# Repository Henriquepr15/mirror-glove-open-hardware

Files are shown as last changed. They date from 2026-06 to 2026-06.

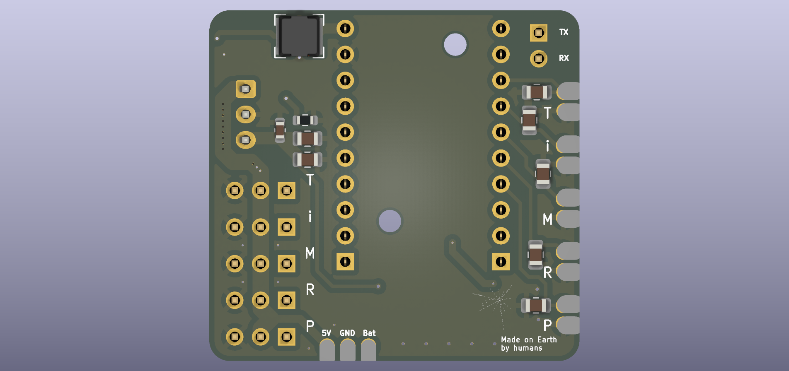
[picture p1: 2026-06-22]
hardware/images/pcb_3d_bottom_render.png

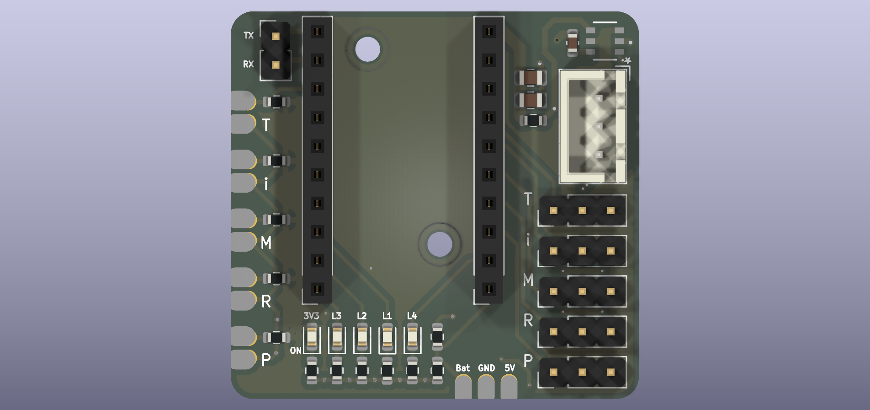
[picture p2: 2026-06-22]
hardware/images/pcb_3d_top_render.png

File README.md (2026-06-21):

# Mirror Glove Open Hardware

Mirror Glove is an open hardware wearable interface designed for finger motion capture using flexible resistive sensors, an ESP32-C6 Super Mini microcontroller, signal conditioning circuitry, firmware, and a labeled gesture dataset for assistive technology research.

The project was developed as an experimental platform for acquiring analog signals generated by finger flexion. The system uses five flexible sensors positioned on a glove, one for each finger, and converts finger movement into measurable electrical signals. These signals can be used for gesture analysis, motion mirroring, actuator control experiments, and preliminary gesture classification in external computational environments.

## Project goals

* Capture finger motion using five flexible resistive sensors.
* Condition analog signals using voltage dividers and passive RC low-pass filtering.
* Read sensor signals using an ESP32-C6 Super Mini.
* Organize sensor data into a structured gesture dataset.
* Support experimental motion mirroring using a transmitter and receiver architecture.
* Provide open hardware documentation for assistive technology, wearable interfaces, embedded systems, and prosthetics research.

## Repository structure

* `hardware/`: PCB design files, schematics, layout images, Gerber files, and hardware-related documentation.
* `firmware/`: ESP32 firmware for the glove transmitter and receiver/actuator unit.
* `docs/`: build instructions, calibration instructions, testing procedures, and operation notes.
* `bom/`: bill of materials with component specifications and quantities.
* `data/`: raw and processed datasets generated from the Mirror Glove.
* `analysis/`: scripts and notebooks used for signal analysis, PCA, machine learning models, and result generation.
* `figures/`: images, diagrams, plots, confusion matrices, and graphical outputs used in the manuscript.

## Intended audience

This project is intended for undergraduate students, researchers, hardware developers, embedded systems developers, assistive technology researchers, and engineers working with wearable interfaces, gesture capture, rehabilitation engineering, robotics, and experimental prosthetics.

## Skills required

* Soldering and PCB assembly: intermediate to advanced.
* ESP32 firmware development: intermediate.
* KiCad or PCB design review: intermediate.
* Python-based signal analysis: basic to intermediate.
* Wearable prototype assembly: basic to intermediate.

## Hardware overview

The Mirror Glove prototype consists of a wearable glove with five flexible resistive sensors connected to a custom PCB. Each sensor is associated with one finger: thumb, index, middle, ring, and pinky. The analog signal from each sensor is conditioned using a voltage divider and passive RC low-pass filtering before being read by the ESP32 analog inputs.

The hardware was designed to support data acquisition, gesture recording, signal analysis, and future expansion for actuator control or wireless motion mirroring using ESP32-based communication.

## Software overview

The firmware is divided into two main modules:

1. Glove transmitter firmware: reads the five flexible sensors and organizes the sensor values.
2. Receiver/actuator firmware: receives sensor data and can convert proportional finger motion values into actuator commands.

Artificial intelligence and gesture classification are not embedded in the ESP32 firmware in the current version. Machine learning analyses are performed externally using the collected dataset.

## Dataset

The dataset contains labeled samples collected from the Mirror Glove sensors during gesture execution. Each sample includes time information, gesture labels, and the readings from the five flexible sensors. The dataset is intended for signal analysis, exploratory visualization, and preliminary supervised gesture classification.

## Documentation status

This repository is under active organization for submission to the Journal of Open Hardware. Build instructions, calibration procedures, testing instructions, design files, firmware, datasets, and analysis scripts are being organized to support replication and peer review.

## Licenses

Hardware files are intended to be licensed under the CERN Open Hardware Licence Version 2 - Permissive (CERN-OHL-P-2.0).

Software and firmware files are intended to be licensed under the MIT License.

Documentation is intended to be licensed under Creative Commons Attribution 4.0 International (CC-BY 4.0).

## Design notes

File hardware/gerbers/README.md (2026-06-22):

# Gerber fabrication files

This folder contains the Gerber and drill files exported from the Mirror Glove ESP32-C6 Super Mini PCB design.

These files correspond to the prototype version used for experimental validation and open hardware documentation.

## Important note

The current PCB design is provided as an experimental/as-built prototype version. The KiCad Design Rule Checker reported violations mainly related to custom footprints, courtyard definitions, library matching, and layout details.

The board files are shared to support transparency, review, modification, and replication of the prototype. Before manufacturing a new batch, users should open the project in KiCad, run ERC/DRC checks, review the reported violations, and adjust the design according to the fabrication requirements of the selected PCB manufacturer.

This project is not a certified medical device and the PCB files should not be used for clinical or safety-critical applications without additional validation.

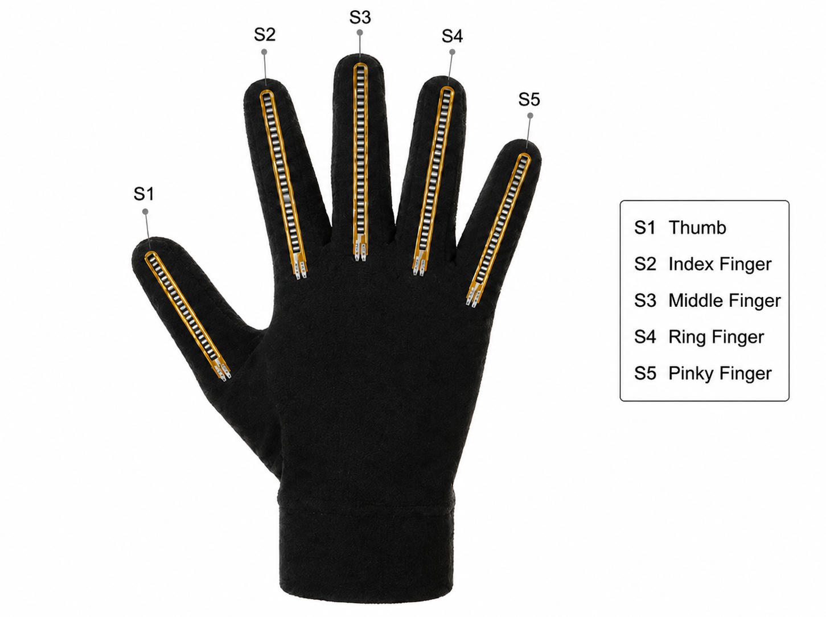
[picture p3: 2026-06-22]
hardware/images/Sensorized Glove Prototype with Flex Sensors.png

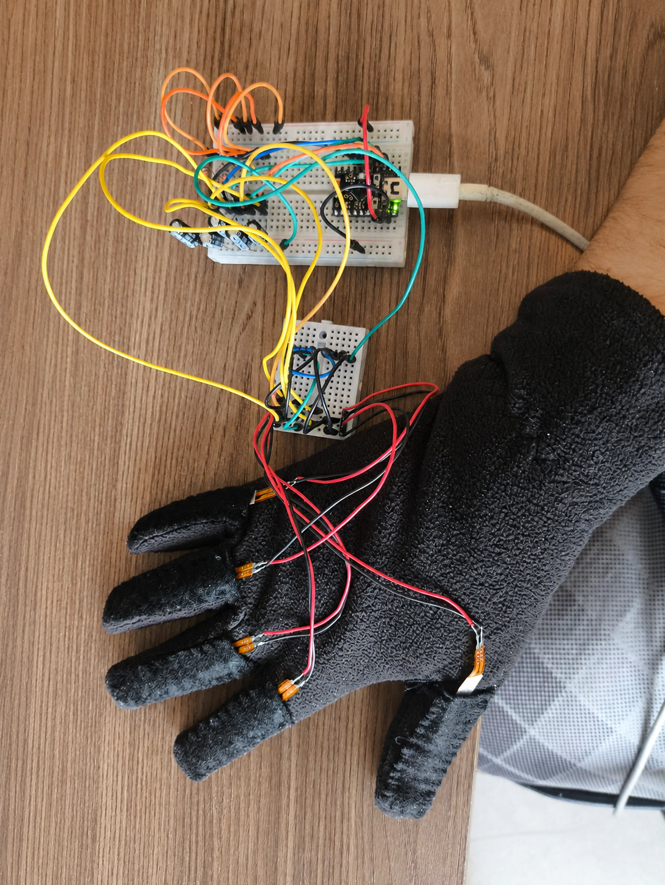
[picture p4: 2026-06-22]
hardware/images/early_prototype_breadboard_glove_1_.jpg

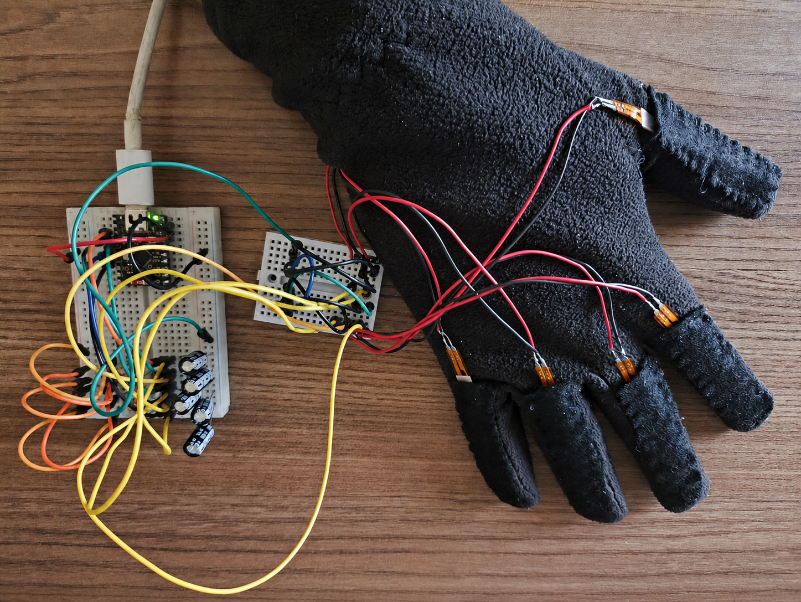
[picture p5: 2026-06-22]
hardware/images/early_prototype_breadboard_glove_2_.jpg

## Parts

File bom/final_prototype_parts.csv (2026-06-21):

Item | Component | Specification | Quantity | Notes
01 | Fabric glove | Base wearable glove | 1 | Physical support for the five flexible sensors
02 | Flexible resistive sensor | Flex sensor for finger bending measurement | 5 | One sensor per finger
03 | ESP32-C6 Super Mini | ESP32-C6 development board | 1 | Main acquisition microcontroller
04 | Mirror Glove printed circuit board | Custom PCB | 1 | Main board for signal conditioning and sensor connections
05 | SMD resistor | 68 kΩ | 5 | Voltage divider resistor for each flex sensor
06 | SMD capacitor | 10 µF | 5 | Passive RC low-pass filtering for sensor channels
07 | SMD capacitor | 100 nF | 2 | Decoupling or auxiliary filtering
08 | SMD capacitor | 4.7 µF | 2 | Decoupling or auxiliary filtering
09 | SMD LED | 0603 package | 5 | Optional visual indication or debugging
10 | Sensor connector | 1x02 connector | 5 | Sensor-to-PCB connection
11 | Pin connector | 1x10 connector | 2 | Board interconnection
12 | JST connector | 1x03 connector | 1 | Power or peripheral connection
13 | Wires or connection cables | Flexible wires | As needed | Used to connect sensors and PCB
14 | USB cable | Compatible with ESP32 board | 1 | Used for programming and power

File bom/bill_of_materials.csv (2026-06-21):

Item | Component | Specification | Unit | Quantity | Category | Used in final prototype | Notes
01 | Fabric glove | Base wearable glove | pcs | 1 | Wearable structure | Yes | Used as the physical support for the flexible sensors
02 | Flexible resistive sensor | Flex sensor for finger bending measurement | pcs | 5 | Sensor | Yes | One sensor positioned on each finger
03 | ESP32-C6 Super Mini | ESP32-C6 development board | pcs | 2 | Microcontroller | Yes | One board for acquisition and one optional board for receiver or actuator tests
04 | Mirror Glove printed circuit board | Custom PCB | pcs | 2 | PCB | Yes | Custom board developed for the Mirror Glove prototype
05 | SMD resistor | 68 kΩ | pcs | 5 | Passive component | Yes | Used in the voltage divider circuits for the flex sensors
06 | SMD capacitor | 10 µF | pcs | 7 | Passive component | Yes | Used mainly for passive RC low-pass filtering and signal stabilization
07 | SMD resistor | 300 Ω | pcs | 4 | Passive component | Yes | Used in auxiliary circuit sections
08 | SMD resistor | 10 kΩ | pcs | 1 | Passive component | Yes | Used in auxiliary circuit sections
09 | SMD resistor | 5.1 kΩ | pcs | 3 | Passive component | Yes | Used in auxiliary circuit sections
10 | SMD resistor | 1 kΩ | pcs | 3 | Passive component | Yes | Used in auxiliary circuit sections
11 | SMD resistor | 100 kΩ | pcs | 1 | Passive component | Yes | Used in auxiliary circuit sections
12 | SMD resistor | 13.7 kΩ | pcs | 1 | Passive component | Yes | Used in auxiliary circuit sections
13 | SMD capacitor | 100 nF | pcs | 2 | Passive component | Yes | Used for decoupling or auxiliary filtering
14 | SMD capacitor | 4.7 µF | pcs | 2 | Passive component | Yes | Used for decoupling or auxiliary filtering
15 | SMD LED | 0603 package | pcs | 5 | Indicator | Yes | Used as visual indicators or debugging elements
16 | Sensor connector | 1x02 connector | pcs | 5 | Connector | Yes | Used to connect the flexible sensors to the PCB
17 | Pin connector | 1x10 connector | pcs | 2 | Connector | Yes | Used for board interconnection
18 | Pin connector | 1x02 connector | pcs | 1 | Connector | Yes | Used for auxiliary connection
19 | JST connector | 1x03 connector | pcs | 1 | Connector | Yes | Used for power or peripheral connection
20 | Test point | PCB test point | pcs | 1 | Testing interface | Yes | Used for measurement or debugging
21 | Inductor | 3.3 µH | pcs | 1 | Power component | Yes | Associated with the power regulation circuit in specific PCB versions
22 | Integrated circuit | LMR51430YFDDCR | pcs | 1 | Power component | Yes | Used in the buck converter section in PCB versions that include power regulation
23 | Wires or connection cables | Flexible wires or jumper cables | m | 10 | Wiring | Yes | Used for sensor and prototype connections
24 | Soldering iron | Electronic soldering tool | pcs | 1 | Assembly tool | No | Used for PCB assembly
25 | Solder wire | Electronic solder wire | pcs | 1 | Assembly tool | No | Used for PCB assembly
26 | Digital multimeter | General-purpose digital multimeter | pcs | 1 | Testing tool | No | Used for continuity voltage and resistance measurements
27 | Power supply or USB port | USB or external power source | pcs | 1 | Power or testing tool | No | Used to power the prototype during tests
28 | USB cable | Compatible with the ESP32 board | pcs | 2 | Programming and power | No | Used for firmware upload and board power
29 | Computer | Computer for firmware and data analysis | pcs | 1 | Development tool | No | Used for programming data acquisition and analysis
30 | Arduino IDE or PlatformIO | Firmware development environment | pcs | 1 | Software | No | Used to develop and upload ESP32 firmware
31 | KiCad | PCB design software | unit | 1 | Software | No | Used for schematic and PCB design
32 | Python | Python programming environment | unit | 1 | Software | No | Used for signal analysis and machine learning experiments
33 | Arduino Uno | Arduino development board | unit | 2 | Development or test board | No | Used in preliminary bench tests
34 | Breadboard | Protoboard for preliminary tests | pcs | 2 | Development tool | No | Used for initial sensor and circuit validation
35 | PTH capacitors | Various through-hole capacitors for tests | pcs | 5 | Development or test component | No | Used in preliminary filtering and validation tests
36 | PTH resistors | Various through-hole resistors for tests | pcs | 5 | Development or test component | No | Used in preliminary voltage divider and validation tests
37 | Adjustable bench power supply | Adjustable laboratory power supply | pcs | 1 | Testing tool | No | Used for controlled power tests
38 | Electrical tape | Insulating tape | roll | 1 | Assembly support | No | Used for insulation and temporary fixation
39 | Servomotor | Hobby servo motor for actuator tests | pcs | 5 | Actuator | Optional | Used for experimental motion mirroring tests

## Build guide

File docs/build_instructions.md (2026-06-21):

# Mirror Glove Build Instructions

This document describes the basic assembly procedure for the Mirror Glove open hardware prototype. The system consists of a wearable glove with five flexible resistive sensors, a custom PCB, signal conditioning components, an ESP32-C6 Super Mini microcontroller, firmware for data acquisition, and optional receiver-side actuator control.

## 1. Required materials

The main materials required to build the Mirror Glove prototype are:

* 1 fabric glove
* 5 flexible resistive sensors
* 1 custom Mirror Glove PCB
* 1 ESP32-C6 Super Mini module
* 5 fixed resistors for voltage dividers
* Capacitors for passive RC low-pass filtering
* Sensor connectors
* Pin headers or board connectors
* Jumper wires or flexible wires
* USB cable
* Computer with Arduino IDE or PlatformIO
* Soldering iron and solder wire
* Multimeter
* Optional: receiver ESP32 board and servomotors for motion mirroring experiments

A complete bill of materials is provided in `bom/bill_of_materials.csv`.

## 2. Sensor positioning on the glove

Place one flexible resistive sensor on each finger of the glove. The sensors should be aligned with the natural flexion axis of the fingers.

Suggested mapping:

* Sensor 1: thumb
* Sensor 2: index finger
* Sensor 3: middle finger
* Sensor 4: ring finger
* Sensor 5: pinky finger

Each sensor should be positioned longitudinally on the dorsal side of the glove so that finger flexion causes mechanical bending of the sensor.

## 3. Sensor wiring

Each flexible sensor is connected as part of a voltage divider circuit. The voltage divider converts the resistance variation of the flexible sensor into an analog voltage that can be read by the ESP32 analog-to-digital converter.

General connection:

* One terminal of the flexible sensor is connected to the supply/reference side of the voltage divider.
* The other terminal is connected to the analog reading node.
* A fixed resistor is connected between the analog reading node and the reference/ground side, according to the selected circuit configuration.
* The analog reading node is connected to one ESP32 analog input.

Repeat this circuit for all five sensors.

## 4. Signal conditioning

A passive RC low-pass filter is used to reduce fast fluctuations and noise in the analog readings. A capacitor is connected between the analog reading node and GND.

The RC filter is intended to attenuate fast oscillations caused by electrical noise, unstable contact, mechanical vibration, and touch-related interference, while preserving the slower signal variations associated with finger flexion.

## 5. PCB assembly

Solder the components onto the Mirror Glove PCB according to the schematic and board layout files provided in the `hardware/` directory.

Recommended assembly order:

1. Solder passive SMD components such as resistors and capacitors.
2. Solder connectors for the flexible sensors.
3. Solder pin headers or connectors for the ESP32-C6 Super Mini module.
4. Inspect all solder joints visually.
5. Use a multimeter to check for short circuits between power and ground.
6. Connect the ESP32-C6 Super Mini to the PCB.
7. Connect the five flexible sensors to the corresponding sensor inputs.

## 6. Firmware upload

Upload the transmitter firmware to the ESP32-C6 Super Mini using Arduino IDE or PlatformIO.

The firmware should perform the following functions:

* Read the five analog sensor channels.
* Associate each sensor value with its corresponding finger.
* Send readings to the serial monitor or store/transmit the data.
* Optionally transmit the values to a receiver board for motion mirroring.

Firmware files are provided in the `firmware/` directory.

## 7. Initial power-on test

Before wearing the glove, perform a basic power-on test:

1. Connect the ESP32 board to the computer through USB.
2. Open the serial monitor.
3. Check whether five sensor readings are being displayed.
4. Move each sensor manually and verify whether the corresponding reading changes.
5. Confirm that no channel is fixed, saturated, disconnected, or unstable.

## 8. Glove integration

After validating each sensor channel individually, attach the sensors permanently or semi-permanently to the glove. The attachment method should allow the sensor to bend naturally with the finger while avoiding excessive mechanical stress at the sensor terminals.

Recommended practices:

* Avoid sharp bends near the sensor terminals.
* Use flexible wires when possible.
* Provide strain relief near connection points.
* Keep sensor cables organized to avoid pulling during finger movement.

## 9. Calibration before use

Before collecting data, calibrate each sensor by recording approximate minimum and maximum ADC values for each finger.

The calibration procedure is described in `docs/calibration.md`.

## 10. Functional test

After assembly and calibration, perform the following functional test:

1. Wear the glove.
2. Open the serial monitor or data acquisition interface.
3. Move each finger individually.
4. Verify whether the expected sensor channel responds.
5. Perform simple gestures such as open hand, closed hand, pointing, pinch, OK gesture, and thumbs-up.
6. Record a short dataset and inspect whether the readings are coherent.

Testing procedures are described in `docs/testing.md`.

## 11. Notes and limitations

This prototype is intended for experimental data acquisition and research in wearable interfaces, assistive technology, gesture analysis, and prosthetics-related studies. It is not a medical device and should not be used for clinical decision-making without further validation, ethical approval, and regulatory assessment.

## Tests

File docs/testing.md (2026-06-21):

# Mirror Glove Testing Procedure

This document describes the basic testing procedure used to validate the Mirror Glove open hardware prototype.

## 1. Purpose

The testing procedure verifies whether the Mirror Glove prototype can acquire coherent signals from five flexible resistive sensors positioned on a wearable glove.

The tests evaluate:

- Electrical continuity.
- Sensor response.
- Analog reading stability.
- Effect of the RC low-pass filter.
- Individual finger response.
- Gesture recording.
- Optional actuator response.

## 2. Electrical inspection

Before powering the circuit:

1. Visually inspect all solder joints.
2. Check the orientation and placement of connectors.
3. Use a multimeter to verify that there is no short circuit between power and ground.
4. Verify continuity between each sensor connector and the corresponding analog input.
5. Inspect loose wires or unstable connections.

## 3. Power-on test

1. Connect the ESP32-C6 Super Mini to the computer using a USB cable.
2. Open the serial monitor or data acquisition interface.
3. Confirm that the firmware starts correctly.
4. Verify whether five sensor channels are displayed.
5. Confirm that no channel is fixed, saturated, disconnected, or showing abnormal noise.

## 4. Individual sensor test

Test each finger sensor separately:

1. Keep the glove still.
2. Move only one finger.
3. Observe whether the expected channel changes.
4. Return the finger to the relaxed position.
5. Repeat the process for all five fingers.

Suggested mapping:

- Thumb
- Index finger
- Middle finger
- Ring finger
- Pinky finger

## 5. Static stability test

With the glove at rest:

1. Keep the hand still for a short period.
2. Record the raw ADC readings.
3. Observe whether the values remain stable.
4. Compare filtered and unfiltered readings when available.

This test helps evaluate whether the RC low-pass filter reduces fast fluctuations and signal instability.

## 6. Gesture test

Perform simple gestures and verify whether the sensor readings change coherently:

- Open hand.
- Closed hand.
- Pointing gesture.
- Pinch gesture.
- OK gesture.
- Thumbs-up gesture.

Each gesture should produce a different combination of sensor readings.

## 7. Dataset recording test

To validate data collection:

1. Define the gesture label before recording.
2. Record a sequence of samples.
3. Save the timestamp, gesture label, and five sensor readings.
4. Repeat the process for all target gestures.
5. Inspect the dataset for missing values, mislabeled samples, or unstable channels.

## 8. Optional receiver and actuator test

If the receiver board and servomotors are used:

1. Upload the receiver firmware to the second ESP32 board.
2. Confirm that the receiver obtains the transmitted sensor data.
3. Connect the servomotors.
4. Map each sensor value to the corresponding actuator.
5. Move each finger and observe whether the corresponding servo responds proportionally.

## 9. Known limitations

The current prototype is intended for experimental validation. The tests verify signal acquisition and preliminary gesture differentiation, but they do not validate clinical use, long-term durability, anatomical accuracy, or medical safety.

Further tests are required to evaluate:

- Long-term sensor stability.
- Repeated wearing and repositioning of the glove.
- Inter-user variability.
- Mechanical durability.
- Wireless communication reliability.
- Actuator response under load.

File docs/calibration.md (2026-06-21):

# Mirror Glove Calibration Procedure

This document describes the basic calibration procedure for the Mirror Glove flexible sensor readings.

## 1. Purpose

The calibration procedure is used to relate the raw analog-to-digital converter readings from each flexible sensor to the approximate motion range of each finger. Since each sensor may present different electrical and mechanical behavior, calibration is required before data collection or actuator control experiments.

## 2. Required setup

Before calibration, make sure that:

- The five flexible sensors are connected to the PCB.
- The ESP32 firmware is uploaded.
- The serial monitor or data acquisition interface is open.
- The five sensor channels are being displayed correctly.
- The glove is positioned on the user’s hand in a stable and repeatable way.

## 3. Minimum and maximum readings

For each finger, record two approximate reference values:

- `ADC_min`: value measured when the finger is in the relaxed or extended position.
- `ADC_max`: value measured when the finger is flexed within the intended range of motion.

This process must be repeated for:

- Thumb
- Index finger
- Middle finger
- Ring finger
- Pinky finger

## 4. Normalization

The sensor reading can be normalized using the following equation:

`normalized_value = (ADC_current - ADC_min) / (ADC_max - ADC_min)`

Where:

- `ADC_current` is the current raw reading.
- `ADC_min` is the minimum reference value.
- `ADC_max` is the maximum reference value.

The normalized value can be used to compare sensors with different raw ranges or to map finger flexion to actuator commands.

## 5. Servo mapping

When the hardware is used for motion mirroring experiments, the normalized value can be mapped to a servomotor angle:

`servo_angle = angle_min + normalized_value * (angle_max - angle_min)`

Where:

- `angle_min` is the minimum allowed servo angle.
- `angle_max` is the maximum allowed servo angle.

The limits must be selected carefully to avoid mechanical stress on the actuator or experimental prosthetic mechanism.

## 6. Calibration recommendations

- Calibrate the glove after wearing it, not before.
- Avoid excessive finger force during calibration.
- Repeat calibration if the glove position changes.
- Repeat calibration if a sensor is removed or repositioned.
- Inspect unstable readings before collecting data.
- Avoid using saturated ADC values as calibration limits.

## 7. Limitations

This calibration procedure provides an approximate proportional representation of finger flexion. It does not directly measure anatomical joint angles and should not be interpreted as a clinical measurement without further validation.

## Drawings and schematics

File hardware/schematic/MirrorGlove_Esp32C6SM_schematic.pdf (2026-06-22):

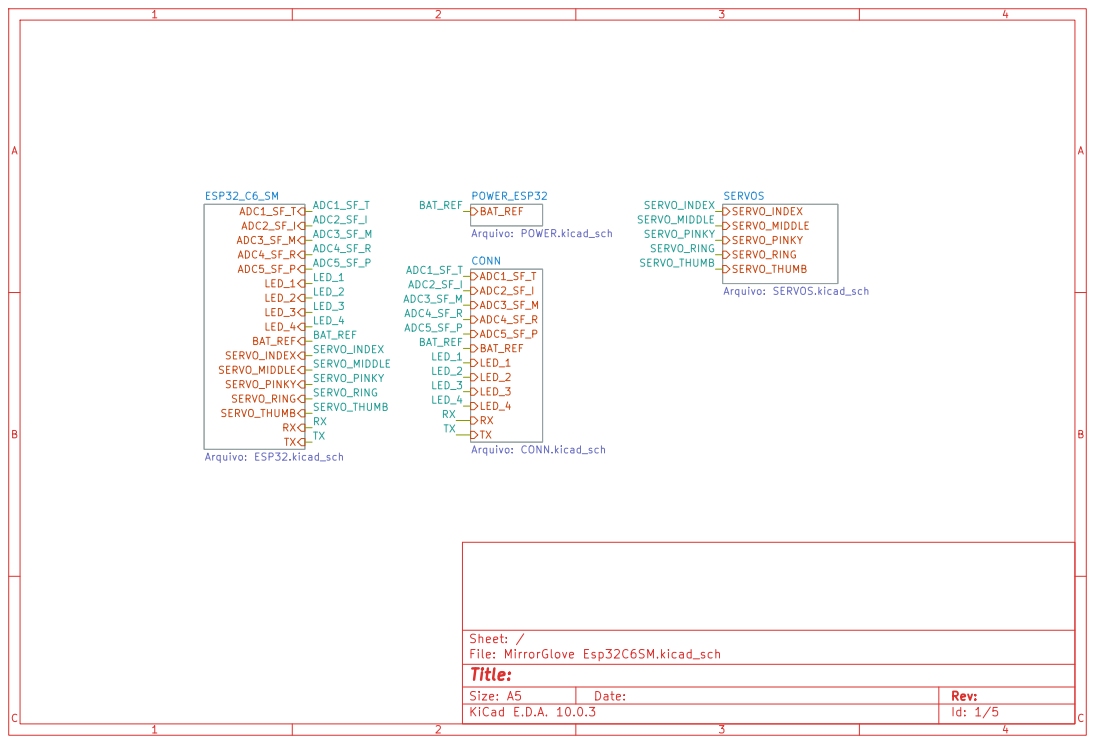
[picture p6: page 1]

Size: A5 | Rev: | C Date:
KiCad E.D.A. 10.0.3 | Id: 1/5

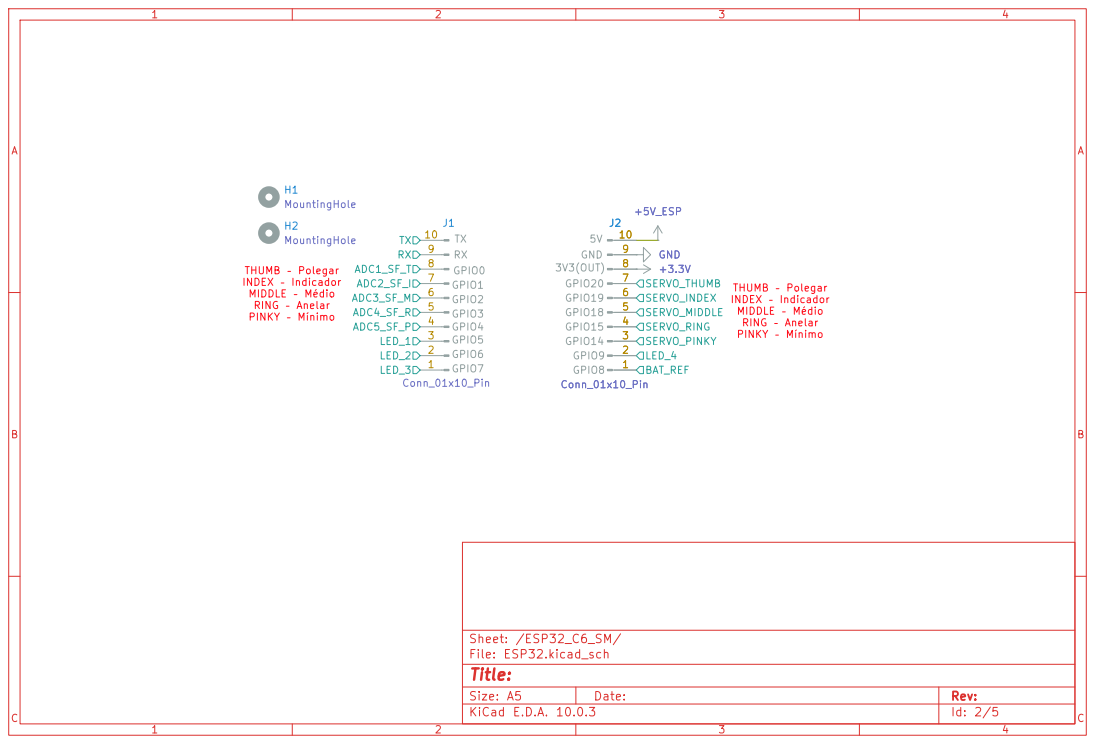
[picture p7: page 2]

Size: A5 | Rev: | C Date:
KiCad E.D.A. 10.0.3 | Id: 2/5

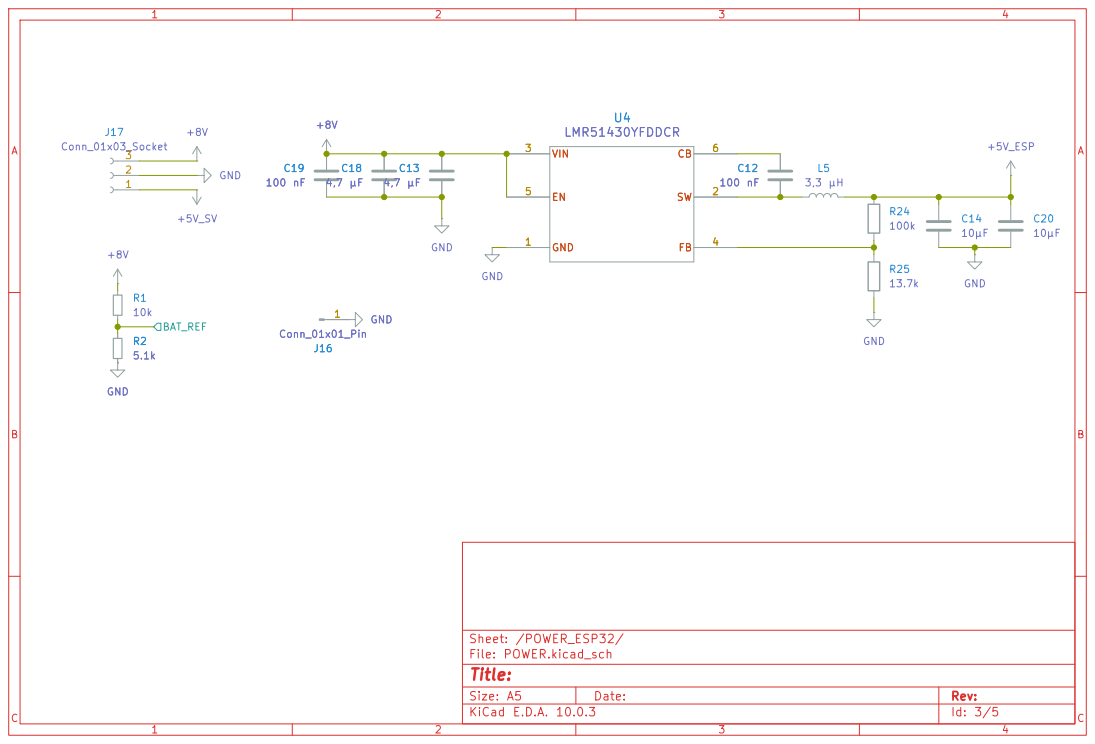
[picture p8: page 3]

Size: A5 | Rev: | C Date:
KiCad E.D.A. 10.0.3 | Id: 3/5

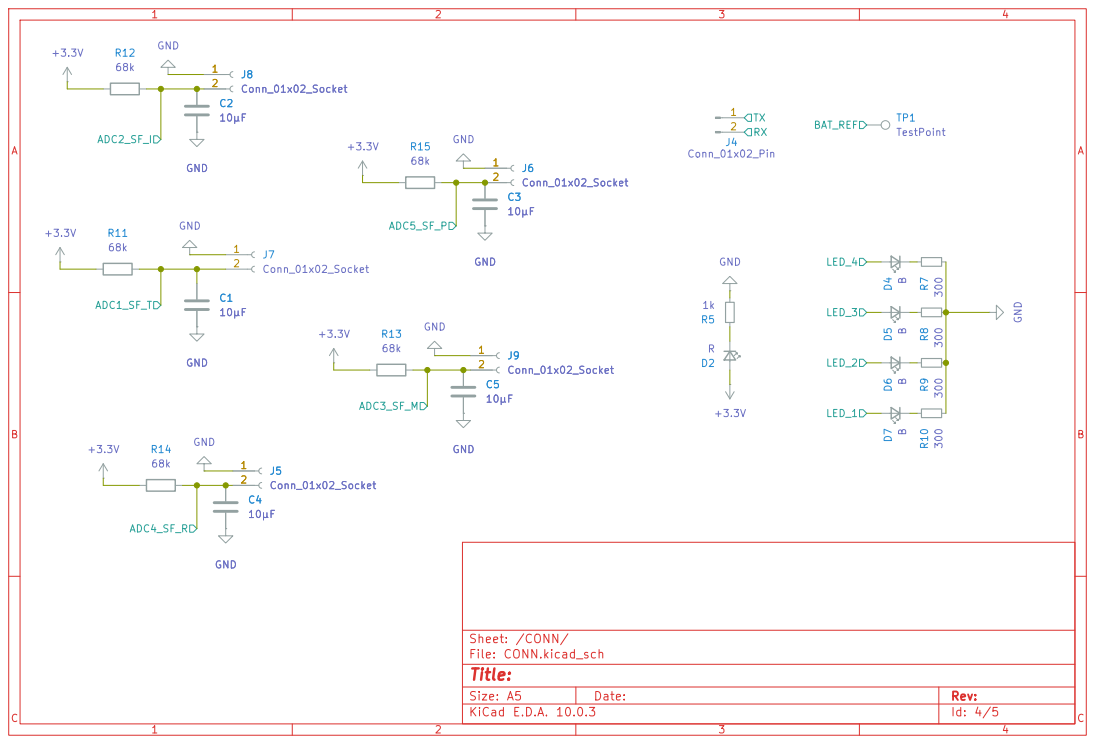
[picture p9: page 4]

Size: A5 | Rev: | C Date:
KiCad E.D.A. 10.0.3 | Id: 4/5

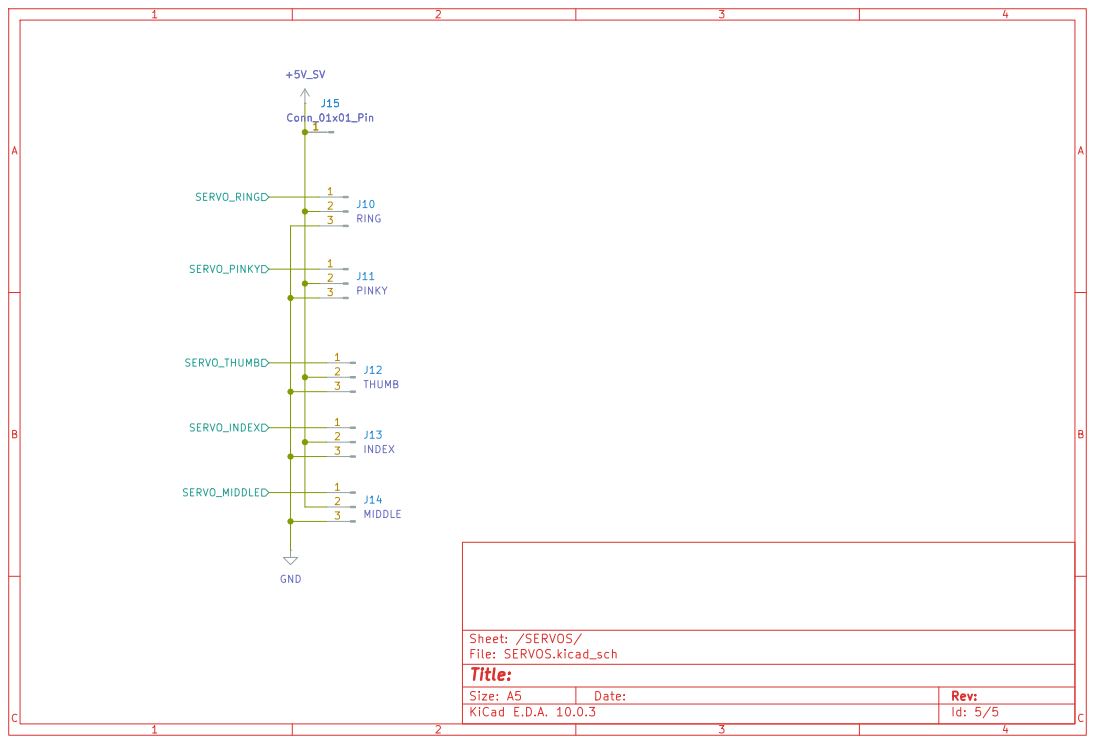
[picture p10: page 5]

Size: A5 | Rev: | C Date:
KiCad E.D.A. 10.0.3 | Id: 5/5

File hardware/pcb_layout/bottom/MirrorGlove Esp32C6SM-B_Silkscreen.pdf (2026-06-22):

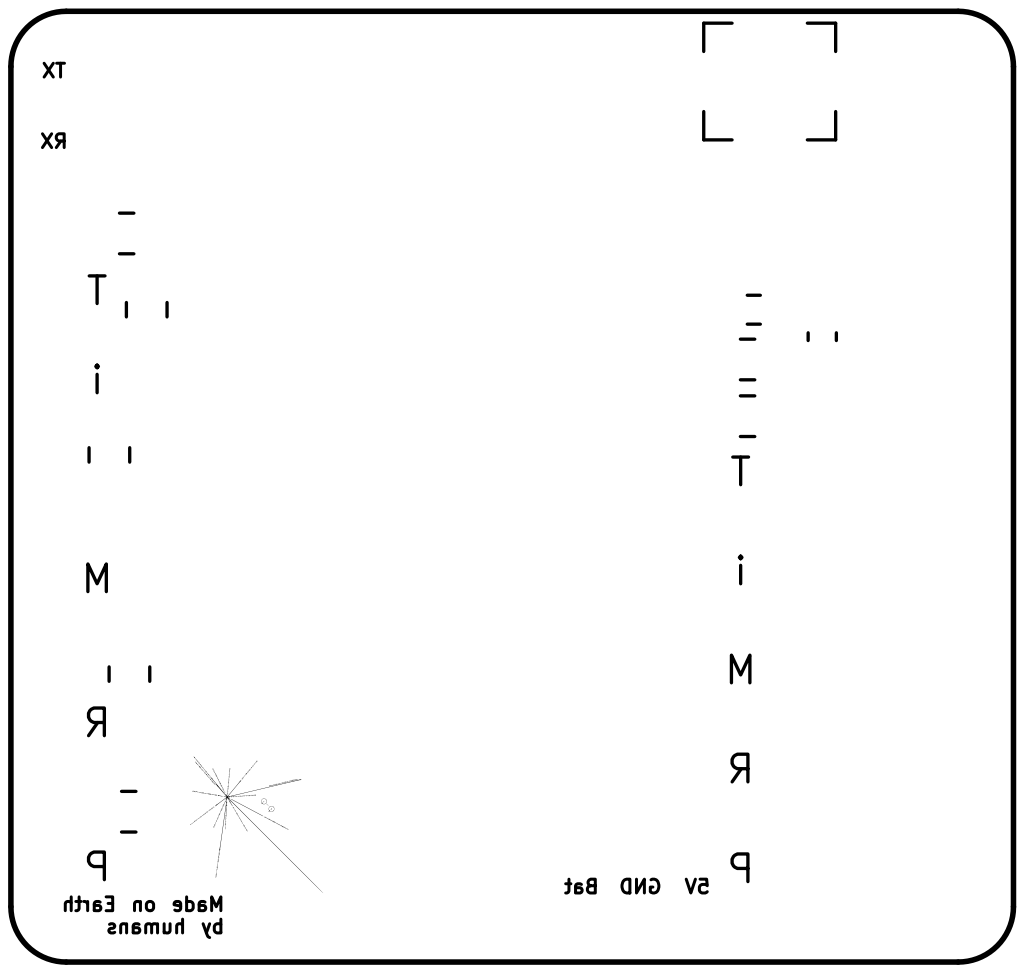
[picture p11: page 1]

TXRX Bat GND 5V iTR

Earth on Made humans by

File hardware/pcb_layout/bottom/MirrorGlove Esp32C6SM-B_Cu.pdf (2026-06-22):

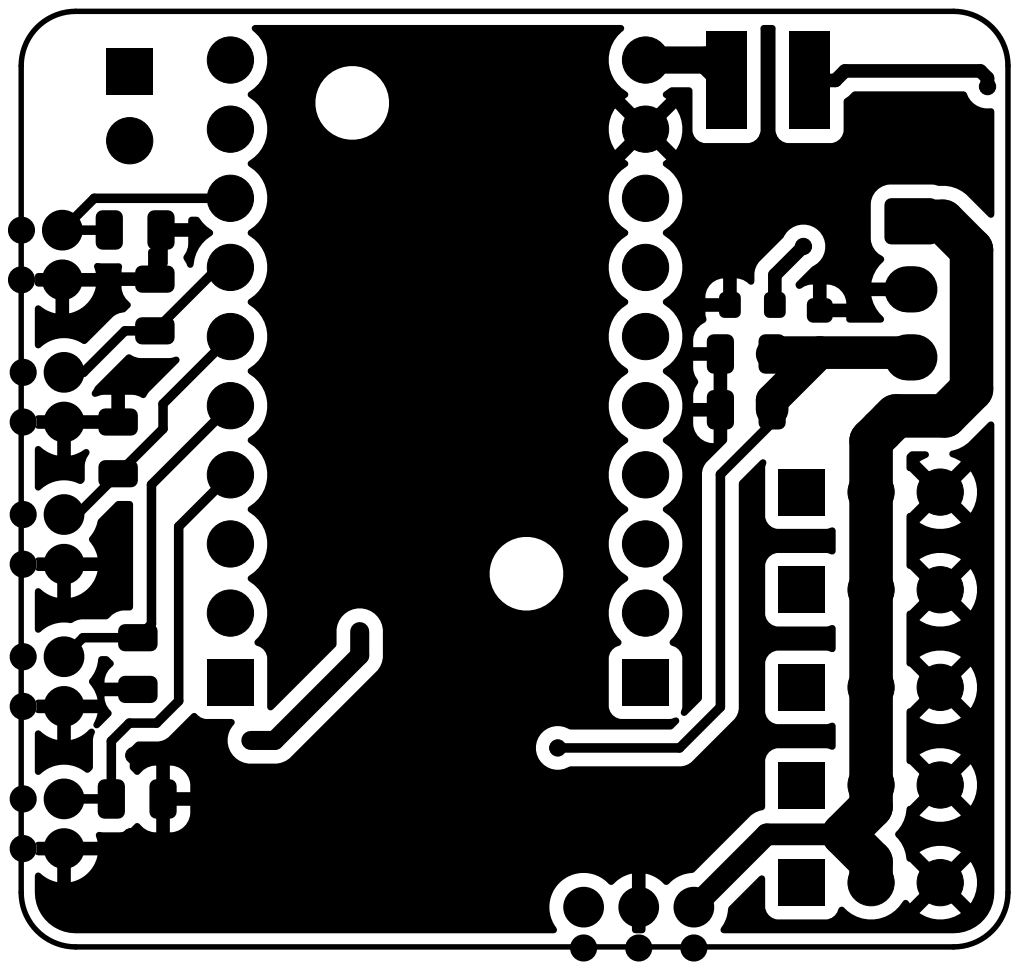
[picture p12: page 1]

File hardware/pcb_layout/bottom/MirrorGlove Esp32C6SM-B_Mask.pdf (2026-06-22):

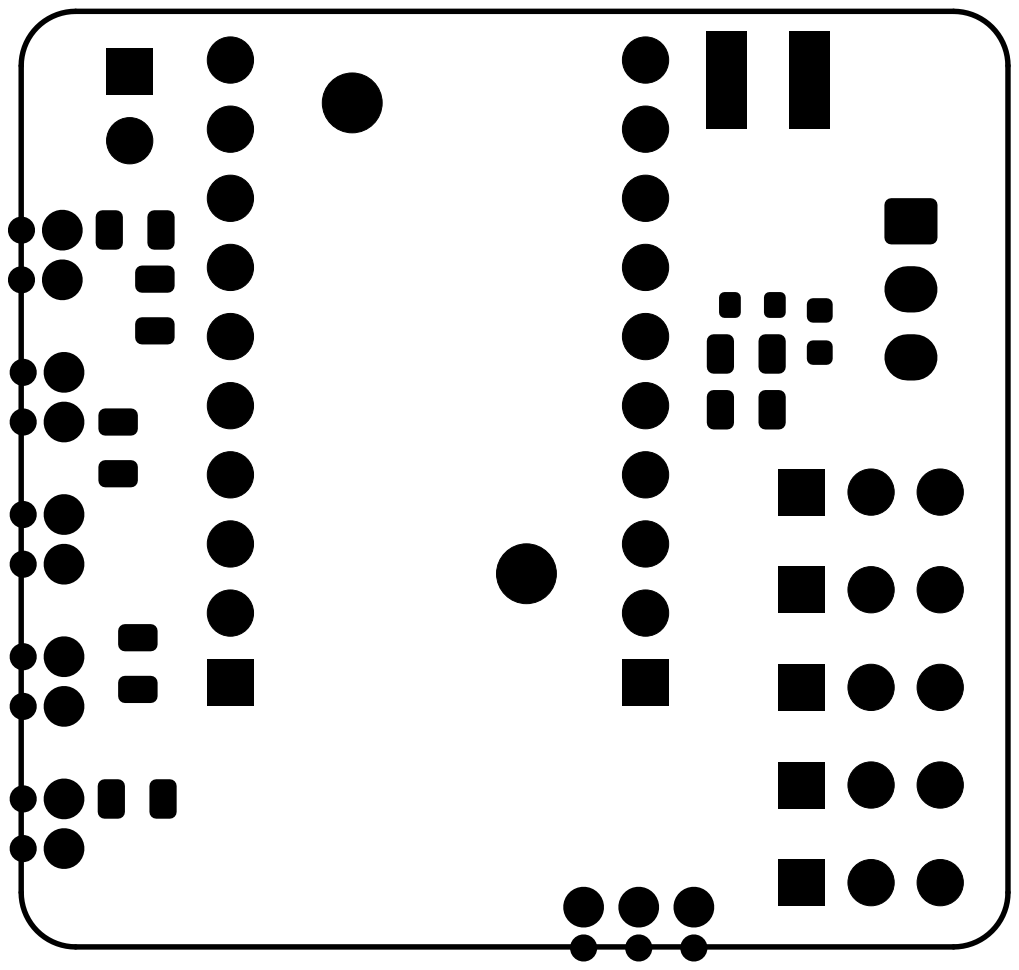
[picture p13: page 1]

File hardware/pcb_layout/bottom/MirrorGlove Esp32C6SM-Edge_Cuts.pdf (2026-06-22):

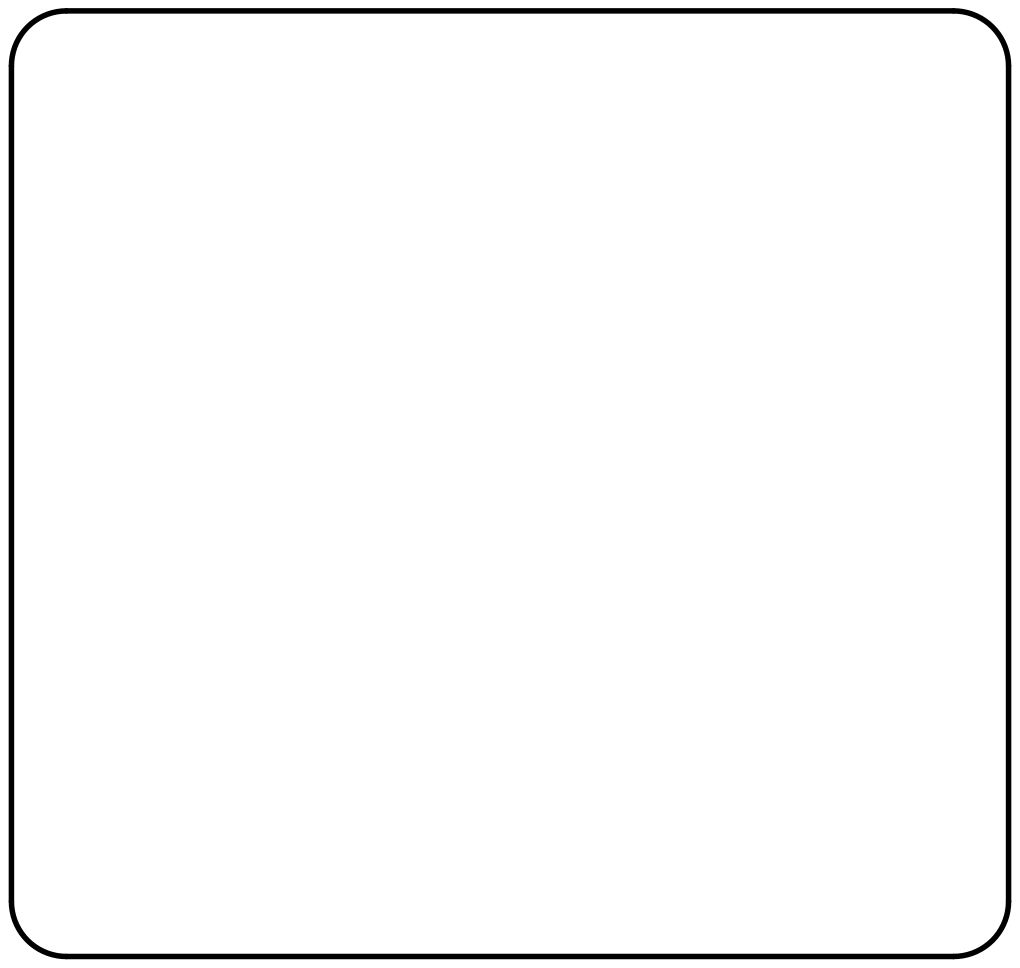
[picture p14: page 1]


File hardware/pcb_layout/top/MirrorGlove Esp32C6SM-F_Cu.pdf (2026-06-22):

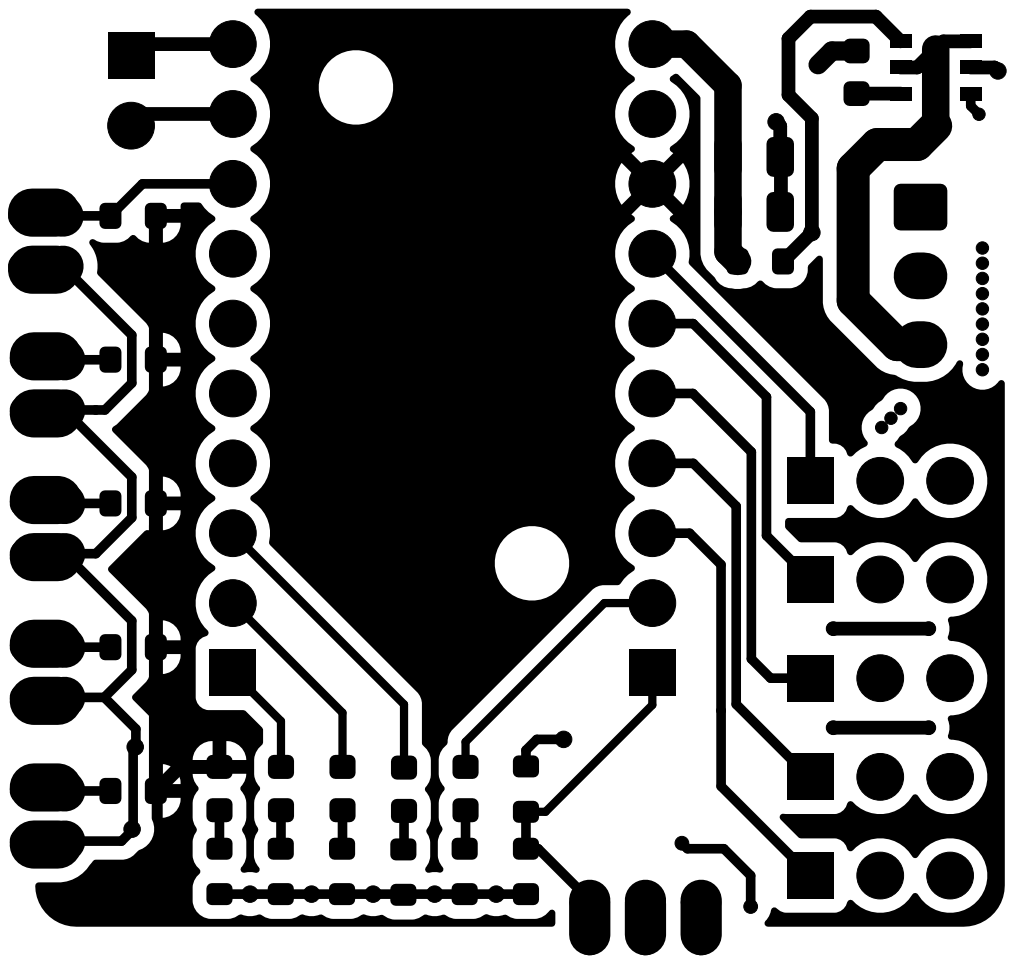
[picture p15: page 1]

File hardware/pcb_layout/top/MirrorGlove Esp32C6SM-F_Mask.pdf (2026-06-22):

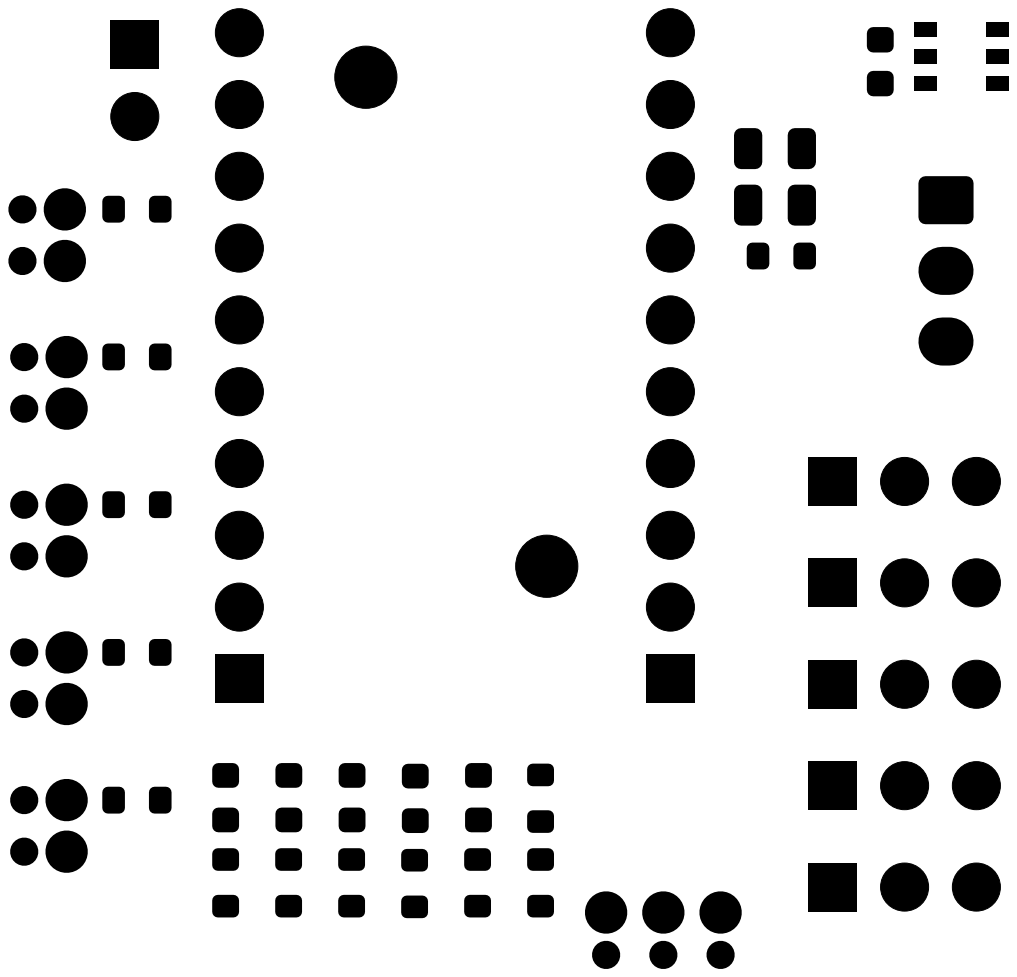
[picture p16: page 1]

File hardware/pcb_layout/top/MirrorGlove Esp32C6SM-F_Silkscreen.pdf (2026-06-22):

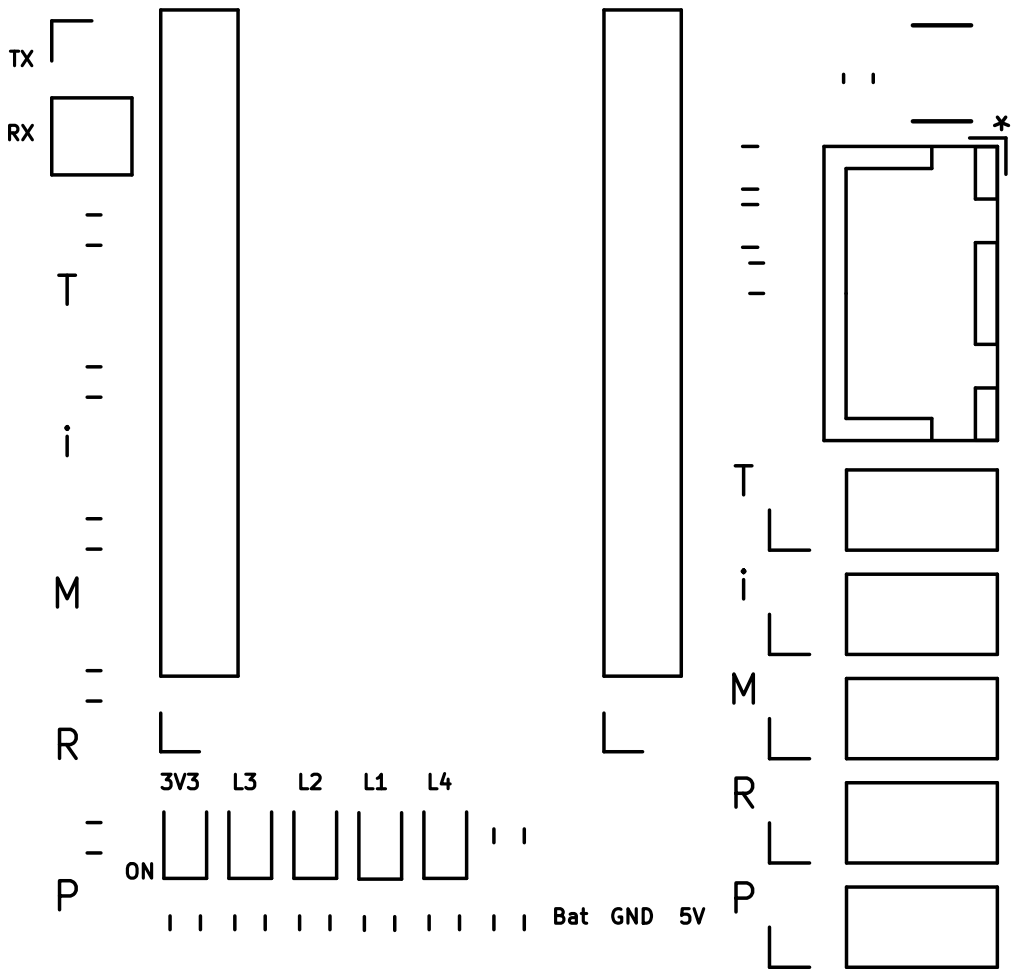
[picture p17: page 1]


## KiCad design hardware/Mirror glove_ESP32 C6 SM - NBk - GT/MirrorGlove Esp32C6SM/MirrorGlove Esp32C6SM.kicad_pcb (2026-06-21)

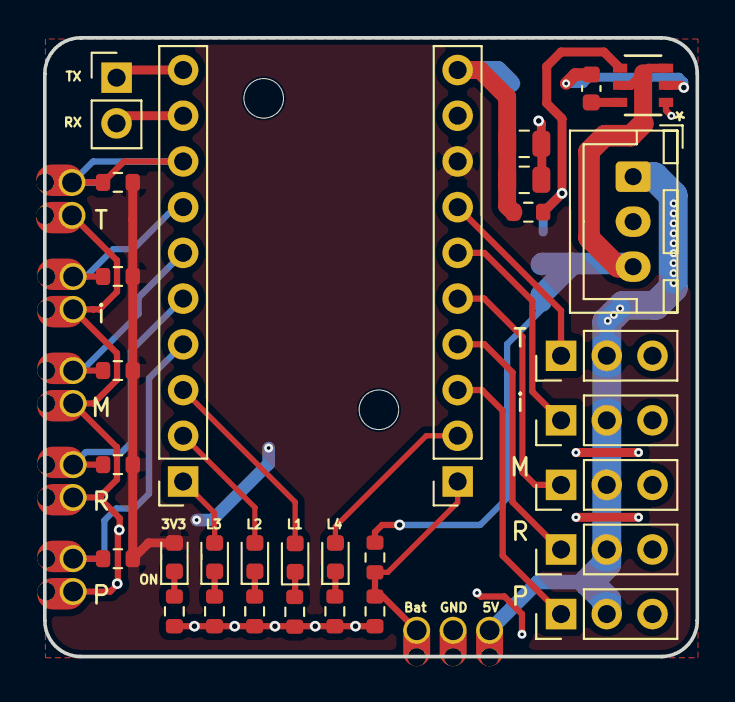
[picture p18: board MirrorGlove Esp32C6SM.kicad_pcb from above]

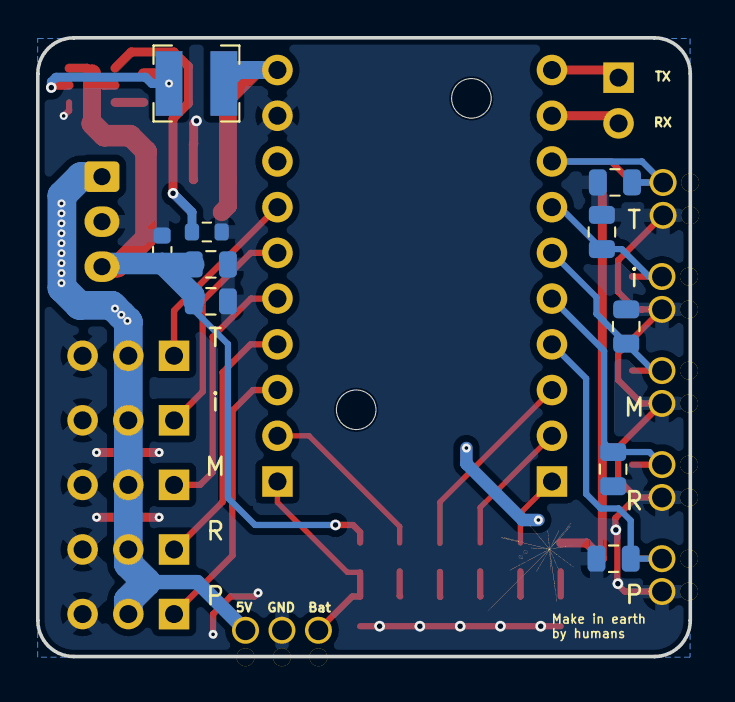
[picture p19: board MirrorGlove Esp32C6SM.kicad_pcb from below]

Board: 2 copper layers, 36.2 x 34.4 mm, 51 parts (10 on the bottom side), 30 nets.

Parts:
C1, C2, C3, C4, C5, C14, C20: 10µF; C_0805_2012Metric
C12: 100 nF; C_0603_1608Metric
C13, C18: 4.7; C_0805_2012Metric
C19: 100; C_0603_1608Metric
D2, D4, D5, D6, D7: R; LED_0603_1608Metric
H1, H2: MountingHole; MountingHole_2.2mm_M2_ISO14580
J1, J2: Conn_01x10_Pin; PinSocket_1x10_P2.54mm_Vertical
J4: Conn_01x02_Pin; PinHeader_1x02_P2.54mm_Vertical
J5, J6, J7, J8, J9: Conn_01x02_Socket; BorderTestPoint-2Pad
J10: RING; PinHeader_1x03_P2.54mm_Vertical
J11: PINKY; PinHeader_1x03_P2.54mm_Vertical
J12: THUMB; PinHeader_1x03_P2.54mm_Vertical
J13: INDEX; PinHeader_1x03_P2.54mm_Vertical
J14: MIDDLE; PinHeader_1x03_P2.54mm_Vertical
J15, J16: Conn_01x01_Pin; BorderTestPoint
J17: Conn_01x03_Socket; JST_XH_B3B-XH-A_1x03_P2.50mm_Vertical
L5: 3,3 µH; L_Bourns-SRN4018
R1: 10k; R_0603_1608Metric
R2: 5.1k; R_0603_1608Metric
R5: 1k; R_0603_1608Metric
R7, R8, R9, R10: 300; R_0603_1608Metric
R11, R12, R13, R14, R15: 33k; R_0603_1608Metric
R24: 100k; R_0603_1608Metric
R25: 13.7k; R_0603_1608Metric
TP1: TestPoint; BorderTestPoint
U4: LMR51430YFDDCR; SOT-23-THIN-6_DDC_TEX-L

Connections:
+3.3V: D2.2 (A), J2.8, R11.1, R12.1, R13.1, R14.1, R15.1
+5V_ESP: C14.1, C20.1, J2.10, L5.2, R24.1
+5V_SV: J10.2, J11.2, J12.2, J13.2, J14.2, J15.1, J17.1
+8V: C13.1, C18.1, C19.1, J17.3, R1.1, U4.3 (VIN), U4.5 (EN)
/ADC1_SF_T: C1.1, J1.8, J7.2, R11.2
/ADC2_SF_I: C2.1, J1.7, J8.2, R12.2
/ADC3_SF_M: C5.1, J1.6, J9.2, R13.2
/ADC4_SF_R: C4.1, J1.5, J5.2, R14.2
/ADC5_SF_P: C3.1, J1.4, J6.2, R15.2
/BAT_REF: J2.1, R1.2, R2.1, TP1.1
/LED_1: D7.2 (A), J1.3
/LED_2: D6.2 (A), J1.2
/LED_3: D5.2 (A), J1.1
/LED_4: D4.2 (A), J2.2
/RX: J1.9, J4.2
/SERVO_INDEX: J2.6, J13.1
/SERVO_MIDDLE: J2.5, J14.1
/SERVO_PINKY: J2.3, J11.1
/SERVO_RING: J2.4, J10.1
/SERVO_THUMB: J2.7, J12.1
/TX: J1.10, J4.1
GND: C1.2, C2.2, C3.2, C4.2, C5.2, C13.2, C14.2, C18.2, C19.2, C20.2, J2.9, J5.1, J6.1, J7.1, J8.1, J9.1, J10.3, J11.3, J12.3, J13.3, J14.3, J16.1, J17.2, R2.2, R5.1, R7.1, R8.1, R9.1, R10.1, R25.2, U4.1 (GND)
unnamed: D2.1 (K), R5.2
unnamed: D4.1 (K), R7.2
unnamed: D5.1 (K), R8.2
unnamed: D6.1 (K), R9.2
unnamed: D7.1 (K), R10.2
unnamed: C12.1, U4.6 (CB)
unnamed: R24.2, R25.1, U4.4 (FB)
unnamed: C12.2, L5.1, U4.2 (SW)

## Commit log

2026-06-21 Add build instructions for Mirror Glove prototype
    This document outlines the assembly procedure for the Mirror Glove prototype, including required materials, sensor positioning, wiring, signal conditioning, PCB assembly, firmware upload, testing, an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
2026-06-21 Add bill of materials for prototype components
    Added a bill of materials for the prototype, detailing components, specifications, quantities, and usage notes.
    [bill_of_materials.csv]
2026-06-21 Add final prototype parts list CSV
    [final_prototype_parts.csv]
2026-06-21 Revise bill of materials to CSV format
    Updated the bill of materials to include CSV formatting and added new components.
    [bill_of_materials.csv]
2026-06-21 Add calibration procedure for Mirror Glove sensors
    This document outlines the calibration procedure for the Mirror Glove flexible sensors, detailing the purpose, required setup, normalization, servo mapping, recommendations, and limitations.
2026-06-21 Add testing procedure for Mirror Glove prototype
    This document outlines the testing procedure for the Mirror Glove prototype, detailing steps for electrical inspection, power-on tests, individual sensor tests, and more.
2026-06-21 Add KiCad design files for Mirror Glove PCB
    Add editable KiCad project, schematic sheets, PCB layout, and custom footprints for the Mirror Glove ESP32-C6 Super Mini hardware version.
    [CONN.kicad_sch, ESP32.kicad_sch, MirrorGlove Esp32C6SM.kicad_pcb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]
2026-06-22 Add exported schematic PDF
    Add schematic PDF exported from the KiCad project for the Mirror Glove hardware.
2026-06-22 Enhance README with Gerber file details and warnings
    Added detailed information about the Gerber files and PCB design considerations.
2026-06-22 Add hardware reference images
    Add PCB 3D renders, sensor positioning diagram, and early breadboard prototype image for Mirror Glove hardware documentation.
2026-06-22 Rename Sensorized Glove Prototype with Flex Sensors.png to Sensorized Glove Prototype with Flex Sensors
2026-06-22 Rename Sensorized Glove Prototype with Flex Sensors to Sensorized Glove Prototype with Flex Sensors.png
